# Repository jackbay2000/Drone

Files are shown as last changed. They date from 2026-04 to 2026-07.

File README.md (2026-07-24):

# Drone Project

## Pinout map

| Component | Signal | Teensy Pin | Wire Color |
|---|---|---|---|
| Optical Flow | VCC | 3V | — |
| Optical Flow | GND | GND | — |
| Optical Flow | MOSI | 11 | white |
| Optical Flow | SCK | 13 | yellow |
| Optical Flow | MISO | 12 | purple |
| Optical Flow | CS | 10 | brown |
| Distance Scanner | Vin | 3V | — |
| Distance Scanner | GND | GND | — |
| Distance Scanner | SDA | 18 | blue |
| Distance Scanner | SCL | 19 | green |
| IMU | Vin | 5V | — |
| IMU | GND | GND | — |
| IMU | SDA | 18 | blue |
| IMU | SCL | 19 | green |
| Reset Switch | Signal | 6-7-8 | — |

Propellers / ESCs (from Drone_Main, X configuration):
CW/CCW are viewed top-down (looking at the propeller from above, drone facing away from you).

                                        FRONT
                                            ^
                                            |
                M1 (CCW)                           M2 (CW)
                Pin 2                               Pin 3
                        \                                 /
                          \                             /
                            \                         /
                              + - - - - - - - - - - +
                              |       DRONE         |
                              |       (FC)          |
                              + - - - - - - - - - - +
                            /                         \
                          /                             \
                        /                                 \
                Pin 4                                 Pin 5
                M3 (CW)                             M4 (CCW)
            REAR-LEFT                           REAR-RIGHT

| Motor | Position | Pin | Spin (top-down) |
|---|---|-----|---|
| M1 | Front-Left | 2 | CCW |
| M2 | Front-Right | 3 | CW |
| M3 | Rear-Left | 4 | CW |
| M4 | Rear-Right | 5 | CCW |

Diagonal motor pairs spin the same direction (M1/M4 = CCW, M2/M3 = CW) to cancel reaction torque, per the standard X-quad mixing in `Controller::_writeMotors`.

## Sensor loop

Everything below runs inside `Drone_Main.ino::loop()`, gated to 250 Hz (`LOOP_PERIOD_US = 4000`). Every tick calls `imu.update()` then `position.update(imu, flow, rangefinder)` before the controller runs.

- **`IMU.cpp`** reads the MPU6050 over I2C and runs a complementary filter (`FILTER_TAU = 0.75`) blending gyro-integrated angle with an accelerometer-derived angle, the latter passed through a median-of-3 filter to reject single-sample spikes. The MPU6050 is physically mounted 90° from the optical flow sensor, so raw IMU axes are remapped into flow-sensor frame (`FLOW_X_SIGN`/`FLOW_Y_SIGN`) before anything downstream sees them. Yaw is gyro-only (no magnetometer) with in-flight bias learning while the vehicle isn't actively yawing, to fight thermal drift.
- **`FlowSensor.cpp`** reads raw `(dx, dy)` motion counts from the PMW3901 over SPI (CS pin 10).
- **`Rangefinder.cpp`** reads slant distance from the VL53L1X over I2C, up to 50 Hz (`setTimingBudget(20)`), rejecting readings outside `0 < d < 4000mm`.
- **`Position.cpp`** fuses all three into world-frame X/Y/Z:
  - **Z**: rangefinder distance corrected for tilt (`d * cos(roll) * cos(pitch)`), low-pass filtered (`ALT_ALPHA = 0.85`), accepted only within `ALT_MIN`-`ALT_MAX` (0.05-3.5 m).
  - **X/Y**: raw flow counts (axis-corrected for the PMW3901's mounting, gyro-compensated to remove apparent motion from rotation, gated against noise below `FLOW_GATE`) are scaled into meters using current altitude and the bench-calibrated `FOCAL_LEN` constant, then rotated by the current yaw estimate into a fixed world frame so waypoint targets stay meaningful regardless of heading.

## Controller loop

Also driven every 250 Hz tick, via `Controller::update()`. No rate loop — deliberately just two cascaded PID stages, since this vehicle flies slow.

- **Safety check**: if `|roll|` or `|pitch|` exceeds 45°, the controller halts immediately (`Controller::halt()` zeros all four ESCs) rather than trying to fight back from a large-angle upset.
- **Outer position loop** (`PositionPID.cpp`), 25 Hz: PID on world-frame X/Y/Z error against the current waypoint, producing a world-frame X/Y control vector and a Z throttle delta added to a fixed hover throttle.
- The world-frame X/Y control vector is rotated by `-yaw` into body frame (`Controller::update`) before being treated as tilt commands — otherwise "pitch forward" would move the vehicle in whatever direction it's currently facing rather than toward the actual world-frame target.
- **Inner attitude loop** (`AttitudeController.cpp`), full 250 Hz rate: PID on roll/pitch angle error against those body-frame tilt commands.
- **Yaw loop** (`YawController.cpp`), full rate: PID on wrapped heading error against the current leg's target yaw (`Drone_Main.ino`'s `_startLeg()` sets this per waypoint — locked to 0° if `keepHeading`, otherwise the bearing to that waypoint).
- **Motor mixing** (`Controller::_writeMotors`) combines throttle/roll/pitch/yaw into each of the 4 motor commands for the X-configuration above, converts to PWM microseconds, and writes them via `PWMServo`.

`Drone_Main.ino` itself just orchestrates the above: reads the kill switch, sequences through `Waypoints.h`'s `FLIGHT_PATH` (advancing once within `WP_RADIUS` of the current target, landing when a waypoint's `z == 0`), and prints telemetry.

## Simulation & test programs

Briefly, for completeness — everything else here supports the firmware in `Drone_Main/`:
- **`Physics_Sim/`** — Python physics + controller simulator, used to Monte Carlo-tune the gains that get pasted into `main.h`.
- **`Position_Test/`** — sensor-only bench sketch (no motors), for calibrating/verifying the IMU, flow sensor, and rangefinder in isolation.
- **`Prop_Test/`** — ESC/motor bench sketch, drives the 4 motors by serial throttle command, no sensors or flight logic involved.

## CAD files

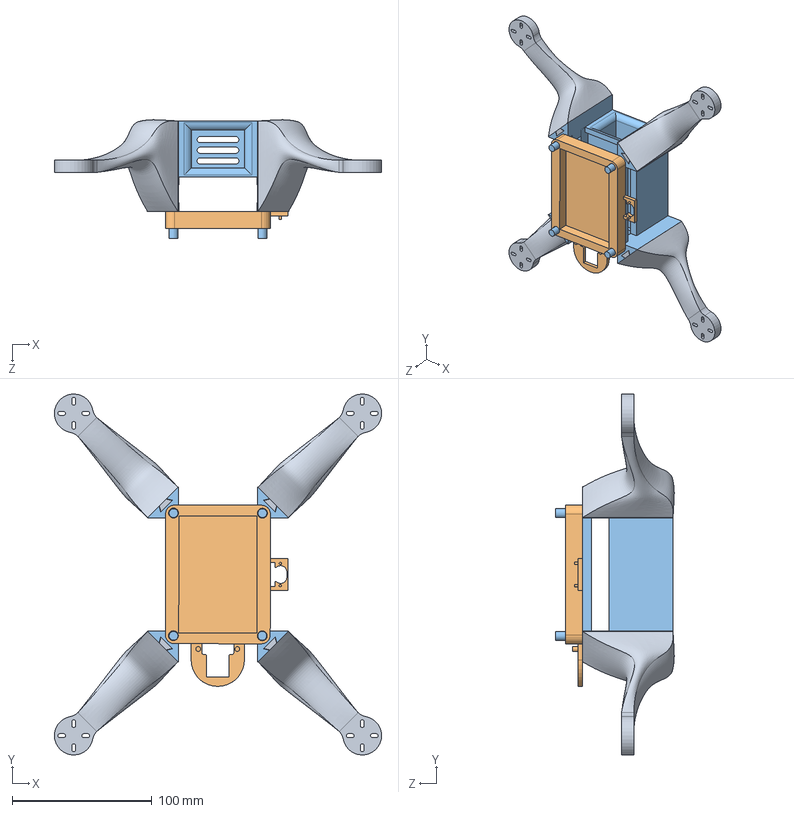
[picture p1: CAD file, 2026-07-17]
Models/Drone_Assembly.SLDASM
233.8 x 257.9 x 84.7 mm
circ-bay-base
top-bb-holder
prop-arm x 4

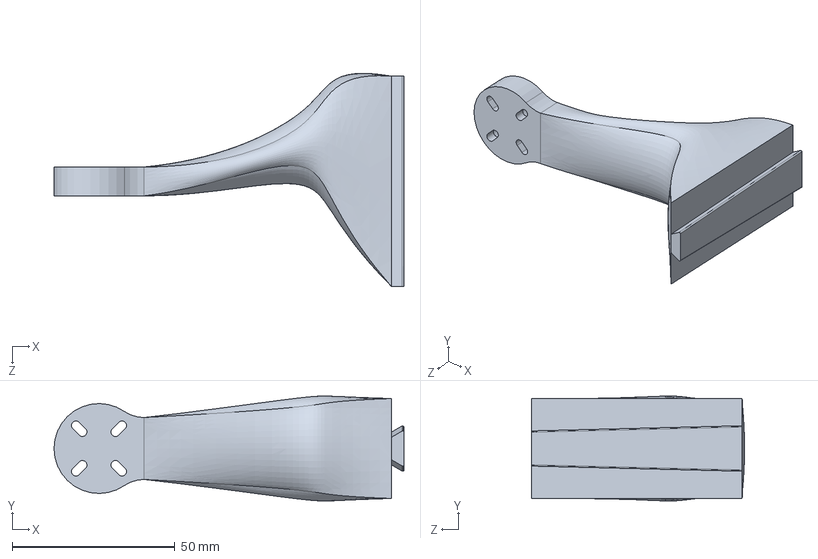
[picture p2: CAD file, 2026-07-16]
Models/prop-arm.SLDPRT
107.7 x 32.3 x 65.7 mm

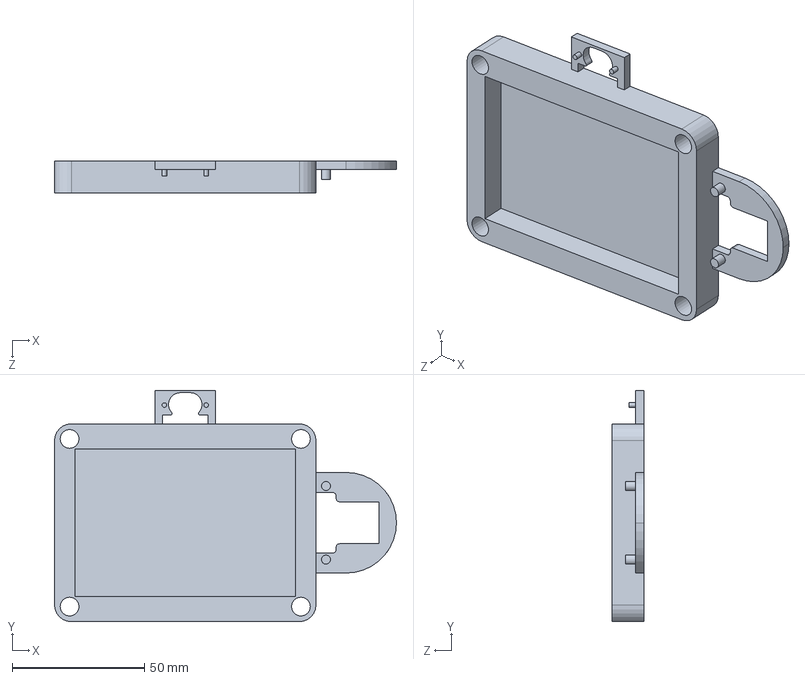
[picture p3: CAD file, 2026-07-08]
Models/top-bb-holder.SLDPRT
129.5 x 87.6 x 12.1 mm

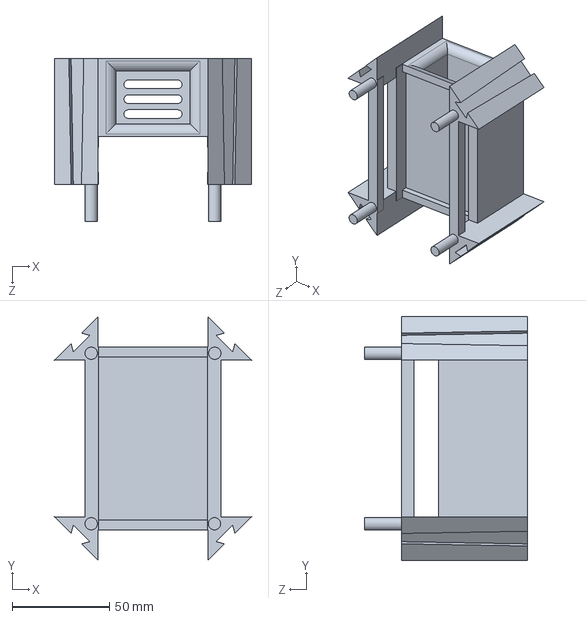
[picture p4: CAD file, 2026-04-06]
Models/circ-bay-base.SLDPRT
101.3 x 125.4 x 83.8 mm

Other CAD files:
Models/circ-bay-base.3mf
Models/circ-bay-base.STL
Models/prop-arm.3mf
Models/prop-arm.STL
Models/top-bb-holder.3mf
Models/top-bb-holder.STL

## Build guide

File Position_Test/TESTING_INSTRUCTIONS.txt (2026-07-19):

TEMPORARY FILE — delete once the tests are done and results are shared back.
Quick-reference for the two bench tests. Full reasoning is in chat if you
need it, this is just the checklist.

===============================================================================
0. UPLOAD
===============================================================================
Upload Position_Test.ino to the board like any other sketch (same wiring as
Drone_Main: MPU6050 + VL53L1X on I2C, PMW3901 CS on pin 10). No props, no
ESCs involved — this sketch never touches motors.

Open a serial connection at 115200 baud, either the Arduino Serial Monitor
or (better, auto-saves to a file) the logger:

    cd Position_Test
    pip install pyserial          (one-time)
    python log_serial.py                    -> logs until you Ctrl+C
    python log_serial.py --seconds 60       -> auto-stops after 60s

Output lands in Position_Test/logs/position_test_<timestamp>.csv.

===============================================================================
TEST 1 — FOCAL_LEN calibration (the important one)
===============================================================================
Goal: find out if Drone_Main/Position.cpp's FOCAL_LEN=30 constant is right.

1. Put the board flat on your DESK (not the floor — desk is more likely to
   be locally level than an old-house floor, and this test doesn't need the
   desk-edge/floor setup, see step 2).
2. Power on / reset it right there. Don't touch it until "# Position_Test
   ready." prints — that's the ~5s level+stationary calibration window.
3. Wait a couple more seconds after "ready" for the Z reading to settle
   (it's low-pass filtered, takes a moment to converge).
4. Lay a tape measure / yardstick along the desk as a straight guide. Mark
   two points as far apart as your desk allows — 1 meter minimum, longer
   is more accurate.
5. IMPORTANT — height floor: keep the board at LEAST 10-15cm above the
   desk surface during the slide. Below 5cm, Position.cpp stops updating
   X/Y entirely (ALT_MIN cutoff) and it'll look like the sensor died when
   it's actually just too low. The flow sensor also needs ~8cm minimum to
   focus at all.
6. Check the desk has visible texture (wood grain, pattern) where the
   sensor will be looking. If it's a plain smooth surface, put a printed
   sheet of paper or a placemat down first — the flow sensor needs texture
   to track against.
7. Note the CURRENT x_m / y_m values right before you start moving (your
   "before" baseline — don't assume it's zero).
8. Slide the board from mark to mark along your measured distance, keeping
   THREE things constant the whole way: height, level (no tilt), and
   heading (no twisting/rotating).
9. Note the ending x_m / y_m values.
10. Whichever axis (x or y) changed by close to your measured slide
    distance is your "forward" direction — compare that number against the
    real distance. The other axis should have stayed near zero (if it
    didn't, that's useful axis-orientation info too).

RECORD: your measured slide distance, and the before/after x_m and y_m.

===============================================================================
TEST 2 — Altitude sanity check (separate, simple, no movement)
===============================================================================
Goal: sanity-check the rangefinder's Z reading against a known height.

1. Stack some books (or anything rigid) to a height you can measure
   precisely with a ruler/tape — floor to where the board's sensor plane
   will sit. Note this measured height.
2. Set the board on top, level, sensor facing straight down at the floor.
3. Power on / reset there, wait for "ready" + a couple seconds to settle
   (same as Test 1 steps 2-3).
4. Read the z_m value.

RECORD: your ruler-measured height vs. the reported z_m.

===============================================================================
TEST 3 — Stationary noise (how jittery are the readings at rest)
===============================================================================
1. Set the board down anywhere, level, stationary.
2. Power on / reset, wait for "ready".
3. Start log_serial.py (or just let it keep logging) for 30-60 seconds,
   completely undisturbed.
4. Stop it (Ctrl+C, or let --seconds auto-stop).

RECORD: just send me the saved .csv file from Position_Test/logs/ — I'll
compute the standard deviation of each column myself.

===============================================================================
WHAT TO SEND BACK
===============================================================================
- Test 1: measured slide distance + before/after x_m, y_m
- Test 2: measured height + reported z_m
- Test 3: the logged .csv file (or just paste its contents)

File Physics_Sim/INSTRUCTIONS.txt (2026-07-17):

===================================================================
  QUADCOPTER PHYSICS SIMULATION — USAGE GUIDE
===================================================================

QUICK START
-----------
  .venv\Scripts\python.exe main.py

First run uses placeholder vehicle parameters (500g, 5" class quad).
Add your real parts progressively — the sim picks them up automatically.

RUNNING SCENARIOS
-----------------
  python main.py --scenario hover          10s altitude hold (default)
  python main.py --scenario step_roll      20° roll step at t=3s
  python main.py --scenario step_pitch     20° pitch step at t=3s
  python main.py --scenario yaw_spin       Continuous 90°/s yaw
  python main.py --scenario altitude_step  Climb from 1m to 2m

  python main.py --scenario waypoints            Fly a CSV waypoint mission

Timestep (default 2ms, smaller = more accurate but slower):
  python main.py --scenario hover --dt 0.001

Use a custom waypoint file:
  python main.py --scenario waypoints --waypoints my_mission.csv

===================================================================
  WAYPOINTS SCENARIO
===================================================================

The waypoints scenario is how you simulate the real flight missions
you plan to fly. The fields (x, y, z, keep_heading) and the flight
behavior (arrival radius, heading logic, landing) exactly match
Drone_Main's mission format — see Drone_Main/Waypoints.h, which is
the file you actually edit to fly this mission on the real vehicle
(Arduino has no filesystem to read a CSV from at runtime, so the
mission there is a small hand-edited C++ array instead).

--- Waypoint file format ---

  inputs/waypoints/waypoints.csv  (default location)
  or any .csv passed via --waypoints

Columns: x_m, y_m, z_m, keep_heading
  x_m, y_m, z_m   Position in the WORLD frame (metres)
                   Origin = takeoff location
  keep_heading     true  → maintain yaw = 0° (nose always faces world +x)
                   false → automatically yaw to face the next waypoint

Lines starting with # are comments and are ignored.

Example:
  0.0, 0.0, 1.0, true     # takeoff / hover
  3.0, 0.0, 1.5, false    # fly forward; nose turns to face this leg
  3.0, 3.0, 1.5, false    # turn left; nose turns to face this leg
  0.0, 3.0, 1.2, true     # lock heading to 0° for the return leg
  0.0, 0.0, 1.0, true     # return home
  0.0, 0.0, 0.0, true     # land (z=0 cuts motors, ends the mission)

--- World frame ---

  +x = forward (the direction the drone faces at takeoff)
  +y = left
  +z = up
  Origin is wherever the drone sits at the start of the simulation.

Waypoints are visited in order. The drone must come within 0.15 m (3D)
of a waypoint before advancing to the next one.

--- Yaw behaviour ---

  keep_heading = true:  yaw is locked to 0°, so the nose always
                        points in the +x direction regardless of
                        which way the drone is flying.

  keep_heading = false: as soon as this waypoint becomes the active
                        target, the drone turns to face it — the
                        heading is the bearing from the previous
                        waypoint (or takeoff point) to this one, set
                        once per leg so it has the whole leg to turn
                        and doesn't jitter as it nears arrival.

--- Landing ---

  A waypoint with z = 0 is a landing waypoint: on arrival the motors
  cut and the mission ends (mission_complete becomes true). Without
  one, the drone just holds position at the last waypoint forever —
  put a z = 0 waypoint last if you want the mission to actually end.

--- Progress output ---

The waypoints scenario prints a status table every 5 seconds:
  t(s)  WP   x      y      z   roll  pitch  yaw
so you can watch the drone work through the mission without opening
the plot window until it finishes.

===================================================================
  DROP-IN FOLDERS
===================================================================

inputs/stl/
  Drop any .stl OR .3mf files from your CAD/slicer here.
  .3mf is strongly preferred: the sim reads infill density and
  material automatically from the slicer config inside the file.
  Supported slicers: PrusaSlicer, BambuStudio, OrcaSlicer, Cura.

inputs/components/component_list.json
  Tell the sim what parts you have and where they sit.
  Edit this file — see the COMPONENT LIST section below.

inputs/controller/
  Drop your .ino / .cpp / .h files here.
  The sim scans them for PID gain variable names (kp_roll, Ki_pitch,
  etc.) and uses those gains. Unrecognised names fall back to defaults.
  No code changes needed when your controller evolves.

===================================================================
  COMPONENT LIST — HOW TO SPECIFY PARTS
===================================================================

Open: inputs/components/component_list.json

Each entry describes one physical component. Example entries:

--- Bought part (motor, battery, ESC) ---
{
    "name": "battery",
    "mass_g": 180,
    "position_m": [0.0, 0.0, -0.025]
}

For bought parts, position_m is the CENTER OF MASS of that part in the
body frame. See COORDINATE SYSTEM section below.

--- 3D-printed part with .3mf file (RECOMMENDED) ---
{
    "name": "frame",
    "mass_g": null,
    "position_m": [0.0, 0.0, 0.0],
    "file_3mf": "frame.3mf",
    "material": "PLA",
    "infill_percent": null,
    "wall_factor": 0.25,
    "rotation_deg": [0.0, 0.0, 0.0]
}

  IMPORTANT: For parts with a geometry file (.3mf or .stl), position_m
  means something DIFFERENT than for bought parts:

    Bought part:    position_m = center of mass of the part
    Geometry part:  position_m = where the MESH ORIGIN (0,0,0 of the
                    exported file) sits in the body frame. The sim
                    computes the true center of mass automatically:
                      CoM = position_m + R @ mesh_center_from_geometry

  If you exported your frame with its origin at the center of the
  motor-mount cross pattern (recommended), then position_m = [0,0,0]
  and no offset is needed. If a sub-part was exported with its own
  local origin (e.g. a camera mount modeled separately), set
  position_m to where that part's origin sits on the assembled drone.

  mass_g:         Set to null — mass is computed from the mesh geometry
                  and effective print density automatically.
  file_3mf:       Filename of the .3mf export from your slicer
                  (drop the file into inputs/stl/).
  material:       Fallback if not found in file. Options:
                    PLA, PETG, ABS, ASA, TPU, NYLON, PETG-CF, PLA-CF
  infill_percent: Fallback if not found in file (e.g. 20).
                  Leave null to read from slicer config automatically.
  wall_factor:    What fraction of the part is solid shell regardless
                  of infill. Default 0.25 (25%) suits 2-3 perimeters.
                  Increase to 0.35-0.40 for very thick-walled parts.
  rotation_deg:   See ROTATION section below.

--- 3D-printed part with .stl file (fallback) ---
{
    "name": "canopy",
    "mass_g": null,
    "position_m": [0.0, 0.0, 0.02],
    "stl_file": "canopy.stl",
    "material_density_kg_m3": 450
}

  material_density_kg_m3: You must set this manually for STL files
  since STL has no print settings. Approximate values:
    PLA  15% infill ~ 380 kg/m³
    PLA  20% infill ~ 435 kg/m³
    PLA  40% infill ~ 620 kg/m³
    PLA solid       ~ 1240 kg/m³
  Rule of thumb: 1240 × (infill% / 100) as a conservative estimate.

===================================================================
  COORDINATE SYSTEM (body frame)
===================================================================

The body frame is fixed to the drone. Its origin is the geometric
center of the frame — the point at the intersection of the diagonals
drawn between opposite motor mounts.

         +x (forward / nose)
          |
  +y ----[O]---- -y (right)
  (left)  |
         -x (rear)

         +z = UP (out of the top of the drone)

All position_m values in component_list.json are specified in this
frame. Note: what position_m refers to depends on the component type:
  - Bought parts (no geometry file): position_m = center of mass
  - Geometry parts (.3mf / .stl):    position_m = mesh origin (0,0,0
    of the exported file). CoM is computed from the mesh automatically.

Examples (bought parts — center of mass positions):
  Battery on underside, centered, 25mm below frame:  [0.0,  0.0, -0.025]
  FC on top, centered, 10mm above frame:             [0.0,  0.0,  0.010]
  Camera on nose, centered, 50mm forward:            [0.050, 0.0,  0.005]
  Front-left motor arm, 80mm out each way:           [0.080, 0.080, 0.0]

Example (geometry part — mesh origin position):
  Frame exported with origin at frame center:        [0.0,  0.0,  0.0]
  Sub-part exported at its own origin, mounted
    30mm forward and 15mm above frame center:        [0.030, 0.0,  0.015]

===================================================================
  EXPORTING FROM SOLIDWORKS FOR USE HERE
===================================================================

To get the best results from .3mf / .stl geometry:

1. In SolidWorks, set the model origin to the CENTER of the frame
   (center of the motor-mount cross pattern). This makes position_m
   = [0, 0, 0] for the frame with no offset needed.

2. Orient your model so that:
     Front of drone  = +X direction in SolidWorks
     Left side       = +Y direction
     Top             = +Z direction

3. Export → Save As → 3MF (preferred) or STL.
   Slice the 3MF in your slicer and re-export so the slicer config
   (infill %, material) is embedded.

If your SolidWorks coordinate system differs, use rotation_deg in the
component entry to realign it. See ROTATION section.

===================================================================
  ROTATION — rotation_deg field
===================================================================

rotation_deg: [rx, ry, rz]

This rotates the mesh from its CAD export orientation into the body
frame (described above) before computing center of mass and inertia.

Rotations are Euler angles in degrees, applied in X→Y→Z order
(extrinsic / fixed-axis).

Common corrections:
  Your SolidWorks X axis points LEFT instead of forward:
    rotation_deg: [0, 0, -90]   (rotate -90° about Z)

  Your model is upside-down (Z points down in SolidWorks):
    rotation_deg: [180, 0, 0]   (flip about X)

  SolidWorks Y is forward, Z is up (common default):
    rotation_deg: [0, 0, -90]   (swap X and Y by rotating -90° about Z)

position_m with geometry files:
  See the IMPORTANT note in the COMPONENT LIST section above.
  In short: position_m is where the mesh origin sits in the body
  frame, NOT the center of mass. The sim computes CoM from geometry.

===================================================================
  CONTROLLER CODE (inputs/controller/)
===================================================================

Drop your .ino file(s) here. The parser looks for variables whose
names contain recognisable keywords:

  Axis keywords:   roll / phi / x,   pitch / theta / y,
                   yaw / psi,         alt / altitude / z
  Term keywords:   kp / P,  ki / I,  kd / D,  rate

Examples that are automatically detected:
  float kp_roll  = 2.5;       → kp_rr  (roll rate P gain)
  double Ki_pitch = 0.05;     → ki_pr  (pitch rate I gain)
  #define KD_YAW 0.0          → kd_yr  (yaw rate D gain)
  rollPID.Kp = 3.0;           → kp_rr
  float kp_alt = 4.0;         → kp_alt (altitude P gain)

The parser is intentionally fuzzy — you don't need to rename your
variables. If a variable is not matched, the sim uses the default
conservative gain for that slot and prints a warning.

To check what was parsed:
  .venv\Scripts\python.exe -c "from controller.arduino_parser import parse_gains; parse_gains()"

===================================================================
  TUNING WORKFLOW
===================================================================

1. Run with defaults first:
     python main.py --scenario hover
   The drone should hover stably (altitude error < 5cm). If it
   diverges, the default PID gains need adjustment.

2. Drop in your component list to get accurate mass / CoM:
     Edit inputs/components/component_list.json

3. Drop in your .3mf files for printed parts for accurate inertia.

4. Drop in your .ino to test your actual gains:
     python main.py --scenario step_roll
   A well-tuned roll step should settle to 20° in < 1s with < 20%
   overshoot, then return cleanly to level.

5. Tune PID gains in your Arduino code, re-drop the .ino, re-run.
   No Python code changes needed between iterations.

===================================================================
  DEPENDENCIES
===================================================================

Activate the virtual environment first:
  .venv\Scripts\activate        (Windows)

Core (already installed):
  numpy, scipy, matplotlib

Optional (for STL/3MF geometry loading):
  .venv\Scripts\python.exe -m pip install trimesh

If trimesh is missing the sim still runs using point-mass
approximations from the mass and position values in component_list.json.

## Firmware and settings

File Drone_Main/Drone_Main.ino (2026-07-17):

#include "main.h"
#include "Waypoints.h"

IMU         imu;
FlowSensor  flow(10);
Rangefinder rangefinder;
Position    position;
Controller  controller;
Gains       gains;

// ── Kill switch ──────────────────────────────────────────────────────────────
static constexpr uint8_t KILL_GND_PIN = 6;
static constexpr uint8_t KILL_SIG_PIN = 7;

enum class DroneState : uint8_t { RUNNING, HALTED, RESETTING };
static DroneState _state;

// ── Mission state ────────────────────────────────────────────────────────────
// FLIGHT_PATH / NUM_WAYPOINTS / WP_RADIUS come from Waypoints.h -- that's the
// only file you need to edit to change the mission.
static int   _currentWP = 0;
static bool  _landed    = false;
static float _legYaw    = 0.0f;   // heading target for the current leg

// ── Init ─────────────────────────────────────────────────────────────────────

// Sets _legYaw for the leg ending at FLIGHT_PATH[wpIndex]: locked to 0 if
// that waypoint wants keepHeading, otherwise the bearing from the previous
// waypoint (or takeoff origin) toward it -- computed once per leg so the
// drone has the whole leg to turn, and doesn't jitter as it nears arrival.
static void _startLeg(int wpIndex) {
  const Waypoint& wp = FLIGHT_PATH[wpIndex];
  if (wp.keepHeading) {
    _legYaw = 0.0f;
    return;
  }
  float fromX = (wpIndex == 0) ? 0.0f : FLIGHT_PATH[wpIndex - 1].x;
  float fromY = (wpIndex == 0) ? 0.0f : FLIGHT_PATH[wpIndex - 1].y;
  float dx = wp.x - fromX;
  float dy = wp.y - fromY;
  if (dx * dx + dy * dy > 1.0e-6f) _legYaw = atan2f(dy, dx);
  // else: degenerate leg (e.g. pure altitude change) -- keep previous heading
}

static void doInit() {
  imu.setup();
  rangefinder.setup();
  flow.setup();
  position.reset();
  position.setup(imu, flow, rangefinder);
  _currentWP = 0;
  _landed    = false;
  _startLeg(_currentWP);
  controller.setup(gains);
}

void setup() {
  Serial.begin(115200);

  pinMode(KILL_GND_PIN, OUTPUT);
  digitalWrite(KILL_GND_PIN, LOW);
  pinMode(KILL_SIG_PIN, INPUT_PULLUP);

  doInit();
  _state = DroneState::RUNNING;
}

// ── Telemetry ────────────────────────────────────────────────────────────────

static void printTelemetry() {
  static unsigned long lastPrint = 0;
  if (micros() - lastPrint < 100000UL) return;
  lastPrint = micros();

  Serial.print("X: ");      Serial.print(position.getX(), 3);
  Serial.print("  Y: ");    Serial.print(position.getY(), 3);
  Serial.print("  Z: ");    Serial.print(position.getZ(), 3);
  Serial.print("  Roll: "); Serial.print(degrees(imu.getRoll()),  1);
  Serial.print("  Pitch: ");Serial.print(degrees(imu.getPitch()), 1);
  Serial.print("  Yaw: ");  Serial.print(degrees(imu.getYaw()),   1);
  Serial.print("  WP: ");   Serial.println(_currentWP);
}

// ── Main loop ────────────────────────────────────────────────────────────────

void loop() {
  bool switchClosed = (digitalRead(KILL_SIG_PIN) == LOW);

  if (switchClosed && _state == DroneState::RUNNING) {
    controller.halt();
    _state = DroneState::HALTED;
    return;
  }

  if (_state == DroneState::HALTED) {
    if (!switchClosed) {
      _state = DroneState::RESETTING;
      doInit();
      delay(10000);
      _state = DroneState::RUNNING;
    }
    return;
  }

  // Timing gate — 250 Hz
  static unsigned long lastLoop = 0;
  static constexpr unsigned long LOOP_PERIOD_US = 4000;
  unsigned long now = micros();
  if (now - lastLoop < LOOP_PERIOD_US) return;
  lastLoop = now;

  imu.update();
  position.update(imu, flow, rangefinder);

  if (_landed) {
    controller.halt();
    printTelemetry();
    return;
  }

  // Waypoint sequencing
  float px = position.getX();
  float py = position.getY();
  float pz = position.getZ();

  const Waypoint& wp = FLIGHT_PATH[_currentWP];
  float ex = wp.x - px;
  float ey = wp.y - py;
  float ez = wp.z - pz;

  if (sqrtf(ex*ex + ey*ey + ez*ez) < WP_RADIUS) {
    if (wp.z == 0.0f) {
      _landed = true;
      controller.halt();
      printTelemetry();
      return;
    }
    if (_currentWP < NUM_WAYPOINTS - 1) {
      _currentWP++;
      _startLeg(_currentWP);
    }
  }

  controller.update(imu, position,
                    FLIGHT_PATH[_currentWP].x,
                    FLIGHT_PATH[_currentWP].y,
                    FLIGHT_PATH[_currentWP].z,
                    _legYaw);
  printTelemetry();
}

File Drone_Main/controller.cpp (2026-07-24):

#include "controller.h"
#include <math.h>

Controller::Controller() {}

void Controller::setup(const Gains& g) {
  _posPID.setup(g.kp_x, g.ki_x, g.kd_x,
                g.kp_y, g.ki_y, g.kd_y,
                g.kp_z, g.ki_z, g.kd_z);

  _attCtrl.setup(g.kp_roll, g.ki_roll, g.kd_roll,
                 g.kp_pitch, g.ki_pitch, g.kd_pitch);

  _yawCtrl.setup(g.kp_yaw, g.ki_yaw, g.kd_yaw);

  const uint8_t pins[] = {2, 3, 4, 5};
  for (int i = 0; i < 4; i++) {
    _esc[i].attach(pins[i], 1000, 2000);
    _esc[i].writeMicroseconds(1000);
  }
  delay(2000);

  _lastMicros = _lastPositionMicros = micros();
}

void Controller::update(IMU& imu, Position& pos, float tx, float ty, float tz, float targetYaw) {
  unsigned long now = micros();
  float dt = (now - _lastMicros) * 1.0e-6f;
  _lastMicros = now;
  if (dt <= 0.0f || dt > 0.1f) return;

  if (fabsf(imu.getRoll()) > 0.785f || fabsf(imu.getPitch()) > 0.785f) {
    halt();
    return;
  }

  // Same fail-safe pattern as the tilt cut above: if altitude data has been
  // stale too long (see Position::altitudeStale()), the position loop would
  // be flying on a frozen Z estimate with no way to know it's wrong. Cutting
  // power is the safe default here, same as an excessive tilt.
  if (pos.altitudeStale()) {
    halt();
    return;
  }

  _cvYaw = targetYaw;

  // Position loop at POSITION_HZ
  float dt_pos = (now - _lastPositionMicros) * 1.0e-6f;
  if (dt_pos >= 1.0f / POSITION_HZ) {
    _lastPositionMicros = now;
    ControlVector cv = _posPID.update(tx, ty, tz,
                                      pos.getX(), pos.getY(), pos.getZ(), dt_pos);
    _cvX          = cv.x;
    _cvY          = cv.y;
    _baseThrottle = _clamp(HOVER_THROTTLE + cv.z, 0.0f, 1.0f);
  }

  // Attitude loop at full rate. _cvX/_cvY are world-frame (PositionPID
  // operates on Position's world-frame x/y against fixed waypoint targets).
  // Rotate into body frame by -yaw before treating them as pitch/roll tilt
  // commands -- otherwise "pitch forward" moves the vehicle in its current
  // heading direction, not toward the world-frame target, and any
  // keep_heading=false leg (nonzero target yaw) can spiral away.
  float yawNow = imu.getYaw();
  float cosY = cosf(yawNow), sinY = sinf(yawNow);
  float bodyX =  _cvX * cosY + _cvY * sinY;
  float bodyY = -_cvX * sinY + _cvY * cosY;

  AttitudeOutput att = _attCtrl.update(imu, bodyX, bodyY, dt);
  float yawCmd       = _yawCtrl.update(imu, _cvYaw, dt);

  _writeMotors(att.roll, att.pitch, yawCmd, _baseThrottle);
}

void Controller::_writeMotors(float roll, float pitch, float yaw, float throttle) {
  float m[4] = {
    _clamp(throttle + roll - pitch + yaw, 0.0f, 1.0f),
    _clamp(throttle - roll - pitch - yaw, 0.0f, 1.0f),
    _clamp(throttle + roll + pitch - yaw, 0.0f, 1.0f),
    _clamp(throttle - roll + pitch + yaw, 0.0f, 1.0f)
  };
  for (int i = 0; i < 4; i++) _esc[i].writeMicroseconds(_pwm(m[i]));
}

void Controller::halt() {
  for (int i = 0; i < 4; i++) _esc[i].writeMicroseconds(1000);
}

float Controller::_clamp(float v, float lo, float hi) {
  return v < lo ? lo : (v > hi ? hi : v);
}

int Controller::_pwm(float normalized) {
  return 1000 + (int)(normalized * 1000.0f);
}

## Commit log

2026-04-04 IMU functional
2026-04-06 added IMU object calls to main, temporarily commented out any references to controller nodes
    [circ-bay-base.3mf, circ-bay-base.SLDPRT, circ-bay-base.STL]
2026-05-09 improved IMU functionality and added propeller test scripts
    [prop-arm.3mf, prop-arm.SLDPRT, prop-arm.STL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]
2026-05-11 added functionality of Optical Flow Sensor and Distance Scanner, integrated them with Drone Main
    [top-bb-holder.3mf, top-bb-holder.SLDPRT, top-bb-holder.STL]
2026-05-12 Functioning position tracking with all sensors
2026-05-24 fixed odd x-y displacement issue by removing a frame rotation. +Y is now forward on aircraft
    [Drone_Main.ino, controller.cpp]
2026-06-05 removed depricated test controller, replaced naming scheme with actual controller module
    [controller.cpp]
2026-06-07 fixed propeller test files. added reset switch functionality, when open cuts power to propellers, when closed again reinitializes all sensors and props, waits 10s, then starts power again.
    [Drone_Main.ino, controller.cpp]
2026-06-17 Added physics simulation (AI sorry) to help with PID tuning
    [circ-bay-base.3mf, circ-bay-base.SLDPRT, circ-bay-base.STL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]
2026-06-18 Slight adjustments to simulator, main.ino now has 4ms delay for timing consistency at 450 Hz
2026-06-19 simplified controller model, changed how gains are passed to the system, removed switch cases for handing different scenarios from controller. Controller now ONLY follow waypoings, stays hovering on 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
2026-07-02 simplified and improved propeller test .ino file, deleted extranious non-working file from previous unsuccessful tests
2026-07-02 finished propeller test, now functions as intended with a user inputted percentage power level in the serial monitor
2026-07-04 fixed drone_main so that the propeller calls and library align with prop_test
2026-07-08 Redesign of top breadboard holder. Previous design had interference between optical flow sensor lense with the cable of the battery. Moved distance scanner mount to the side instead of front and will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
    [top-bb-holder.3mf, top-bb-holder.SLDPRT, top-bb-holder.STL]
2026-07-08 added solidworks assembly of all custom designed housing and frame components (only the 3D printed parts) for simulating purposes
    [Drone_Assembly.SLDASM]
2026-07-15 Updated the physics simulator with final masses for components and assemblies. Added a feature to the IMU to ensure that regardless of exact orientation, an offset will be added so that the IMU will 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
2026-07-16 fixed screw clearance for attaching propellers onto prop_arm (I'm so fucking stupid)
    [prop-arm.3mf, prop-arm.SLDPRT, prop-arm.STL]
2026-07-17 updated assembly with updated prop arms. Added all mass data to physics sim. Updated physics sim to match current controller model. Added monte-carlo sim to physics sim to quickly tune controller mod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
    [Drone_Assembly.SLDASM, waypoints.csv]
2026-07-18 Added sensor refresh rates to simulator. Added sensor noise/dropout to simulator. Fixed a bug which was causing a controller divergance, this bug related to some body -> world and world -> body trans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
    [IMU.cpp, IMU.h, Position_Test.ino]
2026-07-19 Added sensor noise to sim to match real sensor data. Copied over sensor classes from main into a position_test object. Verified all sensors are working as intended and calibrated distance scanner. Fi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
    [position_test_20260718_194253.csv, position_test_20260718_194754.csv, position_test_20260718_195316.csv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]
2026-07-19 Completed calibration for all position sensors, everything working as intended. Decreased upper Z limit to 0.4 meters; the optical flow and distance sensors are the cheapest on the market and start l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
    [position_test_20260719_125858.csv, position_test_20260719_130218.csv]
2026-07-24 updated physics sim with changed sensor clock speeds
2026-07-24 fixed numerous bugs with physics sim including incorrectly loaded parts from components list, incorrectly followed waypoints, incorrectly labeled z limits, etc.
    [position_test_20260718_194253.csv, position_test_20260718_194754.csv, position_test_20260718_195316.csv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]
